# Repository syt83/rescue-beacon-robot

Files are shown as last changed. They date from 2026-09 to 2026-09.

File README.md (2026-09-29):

# Rescue Beacon Robot

RDK X5, Arduino Nano Every, 카메라와 YOLO를 연결해 누운 사람을 찾고
저속 접근한 뒤 멈춰 음향 안내를 재생하는 대회용 ROS 2 프로젝트입니다.
YDLIDAR X4 Pro 코드는 있지만 현재 실물 주행에는 사용하지 않습니다.

## 현재 동작하는 범위

| 기능 | 상태 |
| --- | --- |
| 카메라 → YOLO → ROS 사람 탐지 | RDK X5에서 실측 완료 |
| 카메라 기반 사람 접근, SEARCH → CONFIRM → APPROACH → ALERT | 2026-09-29 바닥 통합 시험에서 접근·ALERT·정지·안내음 확인 |
| LiDAR | `/scan` 발행은 확인했지만 유효 거리 0 문제가 재발해 최종 주행에서 제외 |
| ALERT 이후 정지 유지, 센서/명령 시간 초과 시 정지 | ALERT에서 `/cmd_vel` 선속도·회전속도 0 실측, 오프라인 안전 테스트 통과 |
| Nano Every USB 연결 | 장치 인식 완료 |
| Nano Every 펌웨어와 USB 통신 | 수정 펌웨어 업로드 완료. `READY,1`, `ENC`, `SOUND`, `ACK,BEEP2` 확인 |
| 모터·엔코더 | 왼쪽 방향 설정 수정 후 받침대와 바닥에서 양쪽 전진·정지 확인. 카메라 기반 바닥 통합 주행 확인 |
| ROS ↔ Arduino | 주행 전달을 끈 브리지에서 `/arduino_ready: true`, 정지 상태 `ENC,0,0` 실측 |
| LM393 소리 반응, 스피커 출력 | DFPlayer Pro의 첫 번째 파일 `bbibip.mp3`을 Nano 명령과 ROS 트리거에서 실물 재생 확인. LM393 입력은 별도 시험 필요 |

ROS 제어의 실제 이동 명령은 `mission_controller_node`가
`/cmd_vel`로 발행합니다. 시리얼은 기본적으로 **꺼져 있고**, 시리얼을 켜도
모터 전달은 기본적으로 **꺼져 있습니다**. `ALERT` 상태는 노드 재시작 전까지
유지됩니다.

## 구성

- RDK X5: ROS 2, 카메라, YOLO, LiDAR, 미션 제어
- Arduino Nano Every: PWM/DIR 모터 제어, 엔코더·LM393 입력, DFPlayer Pro 제어
- Cytron MD20A 2개 + RB-35GM 엔코더 모터 2개
- DFPlayer Pro DFR0768 + PAM8403 + 스피커, 128 MB 내장 저장공간

Arduino USB 프로토콜은 `HELLO`/`READY,1`로 펌웨어 버전을 확인합니다.
다른 스케치가 올라가 있으면 ROS 브리지는 모터 명령을 보내지 않습니다.
정확한 핀 제안과 업로드 방법은
[Arduino 펌웨어 안내](firmware/arduino/README.md)에 있습니다.
모터만 확인할 때는 [임시 Arduino 스케치](firmware/arduino/motor_only_diagnostic/motor_only_diagnostic.ino)를
노트북 USB로 업로드하고, [시험 순서](firmware/arduino/README.md)를 따릅니다.

## 실행

1. [대회 실행 및 하드웨어 시험 순서](docs/competition-runbook.md)
2. [코드 전체 안내: 파일별 역할과 읽는 순서](docs/code-guide.md)
3. [ROS 패키지 구조와 토픽](software/ros2/rescue_beacon/README.md)
4. [YOLO 연결](software/perception/README.md)

최종 주행 중 노트북에서 탐지 상자 영상을 보려면
[YOLO 브라우저 모니터](software/perception/README.md#yolo-화면-모니터)를
카메라·YOLO와 함께 실행합니다.

이 장비의 YOLO 런타임과 `best_bayese_640x640_nv12.bin` 모델은 이 저장소 밖에
있습니다. 새 RDK에 복제할 때 두 파일을 따로 준비해야 합니다.

## 구현 범위

현재 거리 판단은 스테레오 깊이가 아니라 YOLO 사람 상자의 높이·폭 비율을
사용합니다. 최종 카메라 주행에는 LiDAR 장애물 정지가 없으며 SLAM/경로
계획도 포함하지 않습니다. LM393 한 개는 소리 유무만 알 수 있으며 방향은 알 수 없습니다.
BNO085 자세 추정과 구조 대상 좌표 보고는 아직 구현되지 않았습니다.
검증된 최종 실행 방법은 [카메라 전용 시험 안내](docs/camera-only-trial.md)를 따릅니다.

## 라이선스

MIT

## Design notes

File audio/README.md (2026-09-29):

# DFPlayer Pro DFR0768 음원 준비

실제로 구매한 모듈은 [DFPlayer Pro DFR0768](https://www.devicemart.co.kr/goods/view?no=13903819)입니다.
**microSD 카드 슬롯이 없고 128 MB 내장 저장공간을 USB-C로 사용합니다.**
[`mp3/0001.mp3`](mp3/0001.mp3)은 약 1.2초짜리 스피커 시험음입니다.
현재 DFPlayer Pro에 복사된 첫 번째 파일은 `bbibip.mp3`입니다. 실물에서
첫 번째 파일 재생 명령으로 이 소리가 나는 것을 확인했습니다.

1. 로봇 메인 전원을 끄고 DFPlayer Pro의 USB-C 단자를 데이터 케이블로 컴퓨터에 연결합니다. Nano Every의 USB 단자가 아닙니다.
2. Windows에서 열린 DFPlayer Pro USB 드라이브의 최상위에 `bbibip.mp3`을 복사합니다. 실제 장비에서는 Windows로 복사를 마쳤습니다. 파일이 여럿이면 첫 번째 파일 번호는 복사 순서에 따라 달라질 수 있으므로 재생 시험으로 확인하세요.
3. 드라이브를 안전하게 꺼낸 뒤 USB-C 케이블을 뽑습니다. Nano에 DFPlayer Pro용 펌웨어가 없다면 [업로드 순서](../firmware/arduino/README.md#빌드와-업로드)를 따릅니다.
4. 다른 시리얼 프로그램을 종료하고 RDK 터미널에 입력합니다.

   ```bash
   cd ~/rescue_ws/rescue-beacon-robot
   python3 scripts/arduino_smoke_test.py --port /dev/ttyACM0 --first-track
   ```

`ACK,BEEP2`는 Arduino가 UART로 첫 번째 파일 재생 명령을 보냈다는 뜻입니다. 스피커에서 실제 소리가 나는지도 확인해야 합니다. 재생 시험 중 바퀴가 움직이면 메인 전원을 즉시 끕니다.

처음 앰프는 뜨거워져 교체했습니다. 교체한 앰프에서는 `PLAY` 버튼으로
“music” 안내음이 들렸고, `--first-track` 시험에서는 원하는 `bbibip.mp3`이
실제로 들렸습니다. `--beep`가 보내는 경로 지정 명령은 이 장비에서 소리를
내지 않았습니다. 따라서 ROS 안내는 검증된 `BEEP,2` → `AT+PLAYNUM=1`을
사용합니다. ROS `/beacon_trigger` 시험에서도 `bbibip.mp3` 재생을 확인했습니다.
현재 Arduino 펌웨어 볼륨 기본값은 20입니다. 다른 파일을
추가하거나 지우면 첫 번째 파일이 바뀔 수 있으므로 다시 들어 보고 확인하세요.

DFPlayer Pro의 USB 파일 복사와 115200 baud AT 명령은 [DFRobot 예제](https://wiki.dfrobot.com/dfr0768/docs/20423)와 [명령 참고서](https://wiki.dfrobot.com/dfr0768/docs/20422)를 따릅니다. 회로도에는 이전 가정인 DFPlayer Mini 심벌이 남아 있어 실제 배선은 Pro 핀 이름으로 다시 확인해야 합니다.

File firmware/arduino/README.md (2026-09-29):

# Arduino Nano Every 펌웨어

## 모터 전원 없이 엔코더 확인

[sensor_only_diagnostic.ino](sensor_only_diagnostic/sensor_only_diagnostic.ino)는
모터 명령을 받지 않고 왼쪽·오른쪽 엔코더의 카운트와 A/B 핀 상태를 보여줍니다.
노트북에 연결한 Nano Every에서만 실행하며, **메인 스위치는 끈 상태로**
유지합니다. 모터 전원과 RDK 전원이 같은 스위치에 묶여 있으므로 RDK에서
실행하는 시험은 아직 진행하지 않습니다.

1. 메인 스위치를 끄고 Nano USB를 Ubuntu 노트북에 연결합니다.
2. Arduino IDE에서 위 파일을 열어 **Arduino Nano Every** 보드와 Nano의
   포트를 선택한 뒤 업로드합니다.
3. 시리얼 모니터를 **115200 baud**로 엽니다. `SENSOR_ONLY_READY` 다음에
   `ENC,<왼쪽>,<오른쪽>,PINS,<LA>,<LB>,<RA>,<RB>,SOUND,<0/1>`이
   반복해서 나오는지 확인합니다.
4. 메인 스위치를 **켜지 않고**, 손으로 왼쪽 바퀴만 천천히 한 바퀴 돌려
   첫 번째 카운트가 변하는지 봅니다. 이어 오른쪽 바퀴만 돌려 두 번째
   카운트가 변하는지 봅니다. 카운트가 증가하는지 감소하는지는 방향에
   따라 달라질 수 있습니다.

카운트가 0에서 바뀌지 않으면 `PINS` 값도 함께 기록합니다. Nano USB만으로
엔코더에 전원이 공급되지 않는 배선일 수 있으므로, 이 결과만으로 엔코더
고장을 판정하지 않습니다. `SOUND`는 회로도의 Arduino_Core 그림에 D10
연결이 표시되지 않아 현재 배선 확인 전에는 참고값일 뿐입니다.

## 모터만 확인하는 임시 스케치

[motor_only_diagnostic.ino](motor_only_diagnostic/motor_only_diagnostic.ino)는
카메라·ROS·RDK 명령 없이 Nano Every에서 MD20A 두 개만 시험합니다.
이전 시험에서 속도 0 명령에도 바퀴가 계속 돌았으므로 **아래 순서 외의 주행
명령은 실행하지 마세요.** 스케치는 부팅 시 PWM을 0으로 설정하지만, 실제
배선이나 드라이버 문제로 바퀴가 도는 것은 소프트웨어가 막지 못합니다.

1. **메인 스위치를 끈 상태에서** Nano USB를 RDK에서 빼서 Ubuntu 노트북에
   연결합니다. Arduino IDE에서 위 `.ino` 파일을 열고 보드를
   **Arduino Nano Every**, 포트를 Nano USB 장치로 선택해 업로드합니다.
   보드가 목록에 없다면 Boards Manager에서 **Arduino megaAVR Boards**를
   설치합니다. 업로드 중에도 메인 스위치는 끈 채 둡니다.
2. Arduino IDE의 시리얼 모니터를 **115200 baud**, 줄 끝은 **Newline**으로
   설정합니다. `STATUS`를 보내 `STATUS,IDLE`이 오는지 확인합니다.
   이때 노트북 USB가 Nano만 켜고 모터 배터리는 꺼진 상태입니다.
3. 차체를 받침대에 고정해 두 바퀴를 띄우고, 손은 바퀴에서 떼고 메인
   스위치에 바로 닿을 수 있게 합니다. 메인 스위치를 켠 뒤 **아무 명령도
   보내지 않고** 확인합니다. 바퀴가 하나라도 돌면 즉시 메인 스위치를
   끄고 더 진행하지 않습니다.
4. 두 바퀴가 가만히 있을 때만 `ARM`을 보내고 5초 안에 `LEFT`를 보냅니다.
   왼쪽만 0.2초 돌고 멈추는지 봅니다. 계속 돌면 메인 스위치를 즉시 끕니다.
   정상이면 다시 `ARM` 다음 `RIGHT`를 보내 오른쪽을 확인합니다.
   `STOP`은 PWM 0 명령이지만, 실제 정지는 눈으로 확인해야 합니다.
5. 시험을 마치면 메인 스위치를 끕니다. 이 임시 스케치는 ROS용
   `READY,1` 프로토콜을 제공하지 않으므로 대회 코드를 쓰려면 아래의
   `rescue_beacon_firmware.ino`를 다시 업로드해야 합니다.

시리얼 모니터에서 보낼 명령은 다음과 같습니다. 한 줄씩 전송합니다.

```text
STATUS
ARM
LEFT
ARM
RIGHT
STOP
```

`ARM`은 다음 한 번의 구동만 허용하고 5초 뒤 만료됩니다. `LEFT`와
`RIGHT`는 PWM 60/255로 최대 0.2초만 구동합니다. 출력 메시지
`PWM_ZERO_COMMAND`는 Arduino가 0을 **명령했다**는 뜻이며, 바퀴가 실제로
멈췄다는 측정값은 아닙니다.

## 구조 로봇 본 펌웨어

`rescue_beacon_firmware/rescue_beacon_firmware.ino`는 RDK X5와 USB 직렬
통신을 하고 Cytron MD20A 2개, 엔코더, LM393, **DFPlayer Pro DFR0768**을 제어합니다.
실제 구매 모듈은 Pro이며, 이전 Mini용 9600 baud 바이너리 명령을
115200 baud AT 명령으로 수정했습니다. 수정한 펌웨어는 다시 업로드해야 합니다.

## 회로도 기준 핀 배치

아래 표는 `hardware/kicad/rescue-beacon-robot.kicad_sch`의
`Arduino_Core` 회로도와 사용자가 공유한 회로도 그림 기준입니다.
실제 배선이 다르면 스케치 맨 위의 핀 상수와 모터 반전 값을 수정한 뒤
업로드하세요.

| Nano Every | 연결 대상 | 코드 상수 |
| --- | --- | --- |
| D3 (PWM) | 왼쪽 MD20A PWM (`PWM_L`) | `LEFT_PWM_PIN` |
| D4 | 왼쪽 MD20A DIR (`DIR_L`) | `LEFT_DIR_PIN` |
| D9 (PWM) | 오른쪽 MD20A PWM (`PWM_R`) | `RIGHT_PWM_PIN` |
| D7 | 오른쪽 MD20A DIR (`DIR_R`) | `RIGHT_DIR_PIN` |
| D2 / D5 | 왼쪽 엔코더 A / B | `LEFT_ENC_A_PIN` / `LEFT_ENC_B_PIN` |
| D6 / D8 | 오른쪽 엔코더 A / B | `RIGHT_ENC_A_PIN` / `RIGHT_ENC_B_PIN` |
| D10 | LM393 DO용 코드 핀; 제공된 `Arduino_Core` 그림에는 연결 표시 없음 | `SOUND_PIN` |
| TX (D1) | DFPlayer Pro RX | `Serial1` |
| RX (D0) | DFPlayer Pro TX (선택, 현재 응답 미사용) | `Serial1` |
| USB | RDK X5 | `Serial`, 115200 baud |

Arduino와 MD20A 2개, DFPlayer Pro, LM393의 **GND는 공통**으로 연결합니다.
LM393 신호선이 D10에 연결되지 않았다면 `SOUND` 값은 실제 소리 상태를
나타내지 않습니다. 음향 감지 시험 전에 이 신호선을 확인하세요.
MD20A의 모터 전원과 모터는 제품 사양에 맞춰 별도로 연결하세요.
모터 전원선을 Nano의 5V 핀에 연결하지 마세요. DFPlayer Pro와 PAM8403은
적합한 안정된 전원을 사용하세요. PAM8403 입력은 DFPlayer Pro의
DAC 출력(DACL/DACR)에 연결하고, Pro의 L+/L- 또는 R+/R- 스피커 출력을
앰프 입력에 연결하지 마세요. 기존 KiCad의 Mini 심벌은 실제 Pro의
핀 배치를 나타내지 않으므로 실물 핀 이름을 기준으로 확인합니다.

Nano Every 핀 기능은 [Arduino 핀도](https://docs.arduino.cc/resources/pinouts/ABX00028-full-pinout.pdf),
PWM/DIR와 자체 테스트 버튼은 [Cytron MD20A 안내](https://www.cytron.io/p-20amp-6v-30v-dc-motor-driver),
DFPlayer Pro 전원·UART·DAC는 [DFRobot 안내](https://wiki.dfrobot.com/dfr0768/)를
기준으로 확인했습니다.

## 음원

USB-C로 Pro 내장 저장공간의 최상위에 `bbibip.mp3`을 넣습니다. `BEEP,2`는
검증된 첫 번째 파일 재생 명령 `AT+PLAYNUM=1`을 보냅니다. `BEEP,1`의
`AT+PLAYFILE=/bbibip.mp3` 경로 재생은 이 장비에서 소리가 나지 않았습니다.
[음원 복사 순서](../../audio/README.md)를
따르세요. Nano Every의 USB 포트로는 Pro에 파일을 복사할 수 없습니다.
`ACK,BEEP2`는 Arduino가 첫 번째 파일 재생 명령을 전달했다는 뜻이며, 실제 소리가
났는지는 귀로 확인해야 합니다.

## 빌드와 업로드

RDK X5에는 [Arduino CLI](https://arduino.github.io/arduino-cli/latest/installation/)
1.5.1과 `arduino:megaavr` 코어 1.8.8을 `~/rescue_ws` 아래에 설치했습니다.
저장소 최상위 경로에서 다음을 실행하세요. 노트북의 Arduino IDE에서
업로드하려면 보드를 **Arduino Nano Every**로 선택하고 보드를 노트북 USB에
연결해야 합니다.
ROS 시리얼 브리지와 시리얼 모니터는 먼저 종료합니다.
현재 Pro용 스케치는 Nano Every 대상 빌드·업로드와 첫 번째 파일
`bbibip.mp3` 재생을 실물 확인했습니다.

```bash
~/rescue_ws/bin/arduino-cli compile --fqbn arduino:megaavr:nona4809 firmware/arduino/rescue_beacon_firmware
~/rescue_ws/bin/arduino-cli upload -p /dev/ttyACM0 --fqbn arduino:megaavr:nona4809 firmware/arduino/rescue_beacon_firmware
```

업로드에서 `jtagmkII_getsync(): sign-on command: status -1`가 반복되면,
Nano Every의 USB 포트를 1200 baud로 열었다 닫아 업로드 모드로 전환한 뒤
바로 업로드 명령을 재시도하세요. 이 장비에서는 그 순서로 성공했습니다.

```bash
python3 -c 'import serial,time; s=serial.Serial("/dev/ttyACM0",1200,timeout=0.1); time.sleep(0.3); s.close()'
~/rescue_ws/bin/arduino-cli upload -p /dev/ttyACM0 --fqbn arduino:megaavr:nona4809 firmware/arduino/rescue_beacon_firmware
```

현재 이 장비의 Nano Every는 `/dev/ttyACM0`이고 LiDAR는 `/dev/ttyUSB0`입니다.
다른 장비에서는 `ls -l /dev/serial/by-id/`로 포트를 다시 찾으세요.
업로드 후 모터 전원을 끈 상태에서:

```bash
python3 scripts/arduino_smoke_test.py --port /dev/ttyACM0
```

`READY,1`, `ENC,...`, `SOUND,...`가 나와야 합니다. 2026-09-27에 업로드 후
`READY,1`, `ENC,0,0`, `SOUND,0`을 확인했습니다. 이전 스케치의
`Nano Every Ready` 출력이 보이면 업로드가 완료되지 않은 상태입니다.

## 직렬 프로토콜과 안전 동작

| 방향 | 메시지 | 의미 |
| --- | --- | --- |
| RDK → Nano | `HELLO` | 펌웨어 버전 요청 |
| Nano → RDK | `READY,1` | 호환 프로토콜 응답 |
| RDK → Nano | `CMD,<m/s>,<rad/s>` | 차동 구동 명령 |
| RDK → Nano | `BEEP,1` | Pro 내장 저장공간의 `/bbibip.mp3` 재생 요청 |
| RDK → Nano | `BEEP,2` | 실물에서 검증된 첫 번째 파일 재생 요청. ROS 기본 안내 명령 |
| Nano → RDK | `ENC,<left>,<right>` | 엔코더 누적 카운트 |
| Nano → RDK | `SOUND,<0/1>` | LM393 디지털 입력 |
| Nano → RDK | `ACK,BEEP` / `ACK,BEEP2` / `ERR,CMD` | 재생 명령 전달 / 잘못된 주행 명령 |

부팅 시 PWM은 0입니다. 유효한 `CMD`가 0.5초 동안 오지 않으면 PWM을 0으로
만듭니다. 명령 크기가 상한을 넘거나 형식이 틀리면 정지합니다.
이는 소프트웨어 정지 장치이며 실제 시험에서는 모터 전원 차단 수단도
준비해야 합니다.
2026-09-27 신호 GND 선을 재연결한 뒤 바퀴가 속도 0 명령에도 계속 돌아
메인 스위치로 정지했습니다. 이후 사용자가 배선을 다시 하고 양쪽 모터의
직선·곡선·회전 주행과 엔코더 동작을 확인했습니다. ROS 브리지의 1회
전진 명령으로도 양쪽 바퀴가 잠깐 돌고 멈췄습니다. 2026-09-29에는 왼쪽
방향 설정을 수정하고 카메라 전용 바닥 주행의 접근·정지·안내음을 확인했습니다.
배선 오류나 접촉 불량에는
소프트웨어 정지 명령이 통하지 않을 수 있으므로 물리 전원 스위치를
사용할 수 있게 둡니다.

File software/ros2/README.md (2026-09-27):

# ROS 2 소프트웨어

`rescue_beacon/`은 RDK X5에서 실행하는 Python ROS 2 패키지입니다.
실제 구현 노드는 `lidar_nav_node`, `person_follow_node`,
`mission_controller_node`, `serial_bridge_node`입니다.

```bash
cd ~/rescue_ws/rescue-beacon-robot
bash scripts/build_ros.sh
bash scripts/run_mission.sh
```

기본 실행은 Arduino 시리얼과 모터 전달이 모두 꺼져 있습니다.
전체 실행 및 하드웨어 순서는
[대회 실행 안내](../../docs/competition-runbook.md),
노드와 토픽은 [패키지 README](rescue_beacon/README.md)를 보세요.

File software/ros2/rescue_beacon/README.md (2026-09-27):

# Rescue Beacon ROS 2 패키지

RDK X5에서 아래 네 노드가 동작합니다.

```text
/scan ── lidar_nav_node ── /search_cmd_vel ──┐
                                             ├─ mission_controller_node ── /cmd_vel
/rescue_yolo_detections ── person_follow_node ┤                └─ /beacon_trigger
                         └─ /person_cmd_vel ┘
                                                      serial_bridge_node
                                                      └─ Nano Every USB
```

`mission_controller_node`가 최종 `/cmd_vel`의 유일한 정상 퍼블리셔입니다.
상태는 `SEARCH → CONFIRM → APPROACH → ALERT`이며, ALERT는 노드를
재시작할 때까지 유지됩니다. 사람 탐지 입력과 LiDAR 스캔이 오래되거나
유효하지 않으면 정지합니다. 탐색·추적 입력과 시리얼 명령에도 각각
시간 초과 처리가 있습니다.

## 실행 인자

`bash scripts/run_mission.sh`는 저장소 최상위 경로에서 실행합니다.

| 인자 | 기본값 | 의미 |
| --- | --- | --- |
| `enable_person` | `true` | 사람 추적 노드 실행 |
| `enable_serial` | `false` | Arduino USB 연결 |
| `enable_motion` | `false` | 시리얼 브리지가 0 이외의 모터 명령 전달 |
| `serial_port` | `/dev/ttyACM0` | Arduino 포트 |

`enable_motion:=true`는 `enable_serial:=true`와 함께 사용합니다.
시리얼 브리지는 `READY,1` 응답을 받은 뒤에만 `CMD`와 `BEEP`를
보냅니다. 다른 스케치가 설치된 보드에는 모터 명령을 보내지 않습니다.
`/beacon_trigger`는 ALERT 상태를 반복 발행하고, 브리지는 상승 시
한 번만 재생 요청을 보냅니다. 연결이 끊겼다가 복구되면 ALERT 재생을
다시 요청합니다.

## 토픽

| 토픽 | 타입 | 의미 |
| --- | --- | --- |
| `/scan` | `sensor_msgs/msg/LaserScan` | LiDAR 입력 |
| `/rescue_yolo_detections` | `ai_msgs/msg/PerceptionTargets` | YOLO 사람 상자 |
| `/search_cmd_vel` | `geometry_msgs/msg/Twist` | LiDAR 탐색 후보 |
| `/person_cmd_vel` | `geometry_msgs/msg/Twist` | 사람 접근 후보 |
| `/person_detected`, `/person_close` | `std_msgs/msg/Bool` | 탐지와 근접 프록시 |
| `/mission_state` | `std_msgs/msg/String` | 상태 머신 |
| `/cmd_vel` | `geometry_msgs/msg/Twist` | 최종 주행 명령 |
| `/beacon_trigger` | `std_msgs/msg/Bool` | 음향 안내 상태 |
| `/arduino_ready` | `std_msgs/msg/Bool` | 호환 펌웨어 통신 여부 |
| `/arduino_telemetry` | `std_msgs/msg/String` | ENC/ACK/ERR 직렬 메시지 |
| `/sound_detected` | `std_msgs/msg/Bool` | LM393 디지털 입력 |

사람 상자의 높이 비율로 접근을 멈추므로 실제 거리 센서는 아닙니다.
단일 LM393의 소리 입력은 모니터링만 하며 방향 탐색에는 쓰지 않습니다.
하드웨어별 실행 순서는
[대회 실행 안내](../../../docs/competition-runbook.md)에 있습니다.

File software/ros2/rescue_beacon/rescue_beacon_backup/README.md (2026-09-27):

# Rescue Beacon ROS2 Package

RDK X5에서 실행되는 Rescue Beacon Robot용 ROS2 패키지입니다.

현재는 YDLIDAR X4 Pro의 `/scan` 데이터를 이용한
기본 장애물 감지 및 회피 명령 생성 기능을 구현하고 있습니다.

## 현재 구현

```text
YDLIDAR X4 Pro
      ↓
    /scan
      ↓
 lidar_nav_node
      ↓
전방 / 좌측 / 우측 거리 판단
      ↓
   /cmd_vel

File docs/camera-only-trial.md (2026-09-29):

# LiDAR 없이 카메라 사람 접근 시험

이 시험은 X4 Pro가 거리 0만 보고할 때 사용하는 **2초짜리 저속 시험**이다.
YOLO 모델은 `fallen`, `sit`, `standing`을 분류한다. 이 시험에서는 **`fallen`
상자만** 추적한다. 화면에는 시험 대상 한 명만 들어오게 한다.
모터는 초속 0.05m, 회전 초속 0.20rad 이하로 제한한다. 정상 종료와
`ALERT`에서는 약 0.5초 동안 속도를 줄이고, 통신이 끊기면 즉시 정지한다.
위 2초 시험에서는 음원을 재생하지 않는다.

LiDAR 장애물 감지는 이 모드에서 사용하지 않는다. 경로에 물건이 없고,
로봇과 사람 사이가 1~2m일 때만 시험한다. 다른 한 명이 화면 밖에서
메인 스위치를 바로 끌 수 있어야 한다. 배터리가 뜨겁거나 부풀었거나
이상한 냄새가 나면 실행하지 않는다.

RDK 터미널을 다음 순서로 연다. LiDAR 터미널과 기존 미션 터미널은 종료한다.

| 터미널 | 실행 명령 |
| --- | --- |
| 1 카메라 | `cd ~/rescue_ws/rescue-beacon-robot && bash scripts/run_camera.sh` |
| 2 YOLO | `cd ~/rescue_ws/rescue-beacon-robot && bash scripts/run_yolo.sh` |
| 3 영상 | `cd ~/rescue_ws/rescue-beacon-robot && bash scripts/run_yolo_monitor.sh --host 0.0.0.0` |
| 4 시험 | `cd ~/rescue_ws/rescue-beacon-robot && python3 scripts/run_camera_only_trial.py` |

노트북 브라우저에서 `http://<RDK_IP>:8088`을 열고, 누운 사람의 상자에
`fallen`이라고 표시되는지 먼저 확인한다. `sit` 또는 `standing`만 보이면
주행하지 않는다. 터미널 4에서 주의사항을 읽고 `RUN`을
입력하면 Arduino `READY,1` 확인 후 최대 2초 동안만 접근한다. 종료되면
두 바퀴가 실제로 멈췄는지 눈으로 확인한다. `Ctrl+C`나 메인 스위치로도
즉시 중단할 수 있다. 바퀴가 계속 돌면 메인 스위치를 끈다.

`fallen` 상자 높이가 화면의 72% 또는 폭이 75%가 3프레임 연속 유지되면
`ALERT`로 전환해 정지한다. 한 프레임만 커지면 감속하지만 도착으로 확정하지 않는다.
화면 점유율은 실제 거리가 아니다. 이 시험이 움직임과 정지를 확인해도
사람 앞에서 정확한 거리로 멈추는 기능은 검증되지 않는다.

## 사람 앞까지 접근 시험

2초 시험에서 양쪽 바퀴의 이동과 감속 정지, 배터리 온도를 확인했다면 같은
터미널 1~3을 켜 둔 채 터미널 4에서 다음 명령을 실행한다.

```bash
cd ~/rescue_ws/rescue-beacon-robot
python3 scripts/run_camera_approach.py
```

로봇 앞 약 2m에 누운 사람 한 명을 두고 화면에서 `fallen` 표시를 확인한다.
`RUN` 입력 후 `ALERT`가 나올 때까지 같은 저속으로 접근한다. 상자가
정지 기준에 못 미쳐도 Arduino 준비 후 30초에 자동 감속 정지한다.
30초 동안 명령상 최대 전진 거리는 약 1.5m이며 실제 이동 거리는 바퀴와
바닥 상태에 따라 달라진다. 사람이 로봇에 닿기 전에 보조자가 화면과
실제 거리를 함께 보고 필요하면 메인 스위치를 끈다. `fallen box` 로그의
폭·높이 비율은 카메라 추정값이며 미터 단위 거리가 아니다.

이전 시험에서는 상자 폭이 36% 부근에서 한 프레임에 69%로 뛰어
`ALERT`가 조기에 발생했다. `fallen` 탐지가 끊기는 현상도 있었으므로,
화면에서 상자가 사라진다면 로봇은 멈췄다가 다시 탐지할 때 접근한다.
조명·자세·카메라 시야 때문에 모델이 계속 놓치는 경우에는 추론 모델의
데이터와 현장 영상 확인이 필요하다. 임의로 신뢰도 문턱을 낮춰 주행을
계속시키지 않는다.

## 안내음까지 묶은 시험

DFPlayer Pro 첫 번째 파일 `bbibip.mp3`은 Nano 명령과 ROS 트리거로 각각
재생을 확인했다. 두 기능을 한 번에 확인할 때는 같은 터미널 1~3을 켜 두고,
터미널 4에서 아래 명령을 실행한다. 기존 시리얼 브리지·미션이 실행 중이면
먼저 종료한다.

2026-09-29 첫 바닥 통합 시험에서는 전진 명령에 좌우 바퀴가 반대로 돌았다.
Nano 펌웨어의 왼쪽 모터 방향 값을 반전한 뒤, 받침대에서 0.3초 전진 명령으로
양쪽 바퀴의 전진·정지를 확인했다. 이어서 바닥 2초 시험에서 전진·정지,
카메라와 음향을 합친 시험에서 `APPROACH → ALERT`·정지·`bbibip.mp3`
재생을 실제로 확인했다. LiDAR는 이 최종 주행에 사용하지 않는다.

```bash
cd ~/rescue_ws/rescue-beacon-robot
python3 scripts/run_camera_audio_trial.py
```

`RUN` 입력 후 `fallen` 대상에 저속 접근하고, `ALERT`가 되면 감속 정지하며
첫 번째 음원을 재생한다. 30초 안에 ALERT가 되지 않으면 자동 감속 정지한다.
LiDAR 장애물 감지가 없는 시험이므로 경로를 비우고 보조자가 메인 전원
스위치를 바로 끌 수 있게 한다. 종료 뒤 바퀴 정지와 앰프·배터리 온도를
직접 확인한다.

## 정지 거리 측정

카메라 상자 크기는 실제 거리와 일치하지 않는다. 주행 시험을 종료하고
로봇을 원하는 정지 간격(예: 사람과 0.5m)에 놓은 뒤 아래 명령으로
8초 동안 `fallen` 상자 비율과 탐지율을 측정한다. 이 명령은 모터 노드를
실행하지 않는다. 카메라와 YOLO는 켜 둔다.

```bash
source /opt/tros/humble/setup.bash
cd ~/rescue_ws/rescue-beacon-robot
python3 scripts/calibrate_camera_stop.py
```

출력의 영상 프레임 수, fallen 탐지 프레임 수, 폭·높이 중앙값을 보고
정지 기준을 정한다. 누운 사람이 화면에 보이는데도 탐지율이 낮으면
정지 수치를 더 조정하기 전에 카메라 화면과 모델을 확인한다.

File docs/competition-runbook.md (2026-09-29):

# 대회 실행 및 하드웨어 시험 순서

기준 장비는 `/home/sunrise/rescue_ws/rescue-beacon-robot`에 이 저장소가 있고,
ROS 2 Humble/TROS, `~/ydlidar_ros2_ws`,
`~/rdk_model_zoo/samples/vision/ultralytics_yolo/runtime/python/ros_yolo_live.py`,
`~/best_bayese_640x640_nv12.bin`이 설치된 RDK X5입니다.
다른 장비에서는 이 외부 파일과 모델을 따로 준비하세요. 모델은 GitHub
저장소에 포함되지 않습니다.

이전 시험에서 속도 0 명령에도 바퀴가 돌아 메인 스위치로 정지한 적이
있습니다. 이후 사용자가 배선을 다시 연결해 양쪽 바퀴의 직선·곡선·회전
주행과 엔코더 동작을 확인했습니다. 받침대 위에서 ROS 브리지의 1회
전진 명령으로 양쪽 바퀴가 잠깐 돌고 멈춘 것도 확인했습니다.
ROS 회전 명령에서는 두 바퀴가 서로 반대 방향으로 잠깐 돌고 멈췄습니다.
2026-09-29 왼쪽 모터 방향을 수정한 뒤 카메라 전용 저속 바닥 주행에서
사람 접근·ALERT 정지·안내음 재생을 확인했습니다. LiDAR는 이 주행에
사용하지 않았습니다. 전원을 켰을 때 명령 없이
바퀴가 돌면 즉시 메인 스위치를 끄고 시험을 중단합니다.

## 0. 빌드

```bash
cd ~/rescue_ws/rescue-beacon-robot
bash scripts/build_ros.sh
```

빌드가 끝난 뒤에도 각 실행 터미널은 별도로 켜 둡니다. 종료할 때는 각
터미널에서 `Ctrl+C`를 누릅니다.

## 0-1. 메인 전원을 끈 채 엔코더만 확인

엔코더를 다시 독립적으로 확인할 때는 노트북 USB로 Nano를 켜고
[센서 전용 Arduino 스케치](../firmware/arduino/README.md#모터-전원-없이-엔코더-확인)를
사용합니다. 왼쪽·오른쪽 바퀴를 손으로 각각 돌려 엔코더 카운트가 변하는지
확인합니다. 이 스케치에는 모터 구동 명령이 없습니다. RDK와 모터는 같은
메인 스위치에 연결되어 있으므로, Nano만 켤 때는 메인 스위치를 끕니다.

## 1. 모터 전달을 끈 ROS 시험

아래 네 터미널을 순서대로 실행합니다. 미션 실행 기본값은
`enable_serial:=false`이므로 Arduino로 명령을 보내지 않습니다.

| 터미널 | 명령 | 확인할 것 |
| --- | --- | --- |
| 1 카메라 | `cd ~/rescue_ws/rescue-beacon-robot && bash scripts/run_camera.sh` | `/image_left_raw` |
| 2 YOLO | `cd ~/rescue_ws/rescue-beacon-robot && bash scripts/run_yolo.sh` | `/rescue_yolo_detections` |
| 3 LiDAR | `cd ~/rescue_ws/rescue-beacon-robot && bash scripts/run_lidar.sh` | `/scan` |
| 4 미션 | `cd ~/rescue_ws/rescue-beacon-robot && bash scripts/run_mission.sh` | `/mission_state`, `/cmd_vel` |
| 5 YOLO 화면 | `cd ~/rescue_ws/rescue-beacon-robot && bash scripts/run_yolo_monitor.sh --host 0.0.0.0` | 브라우저의 탐지 상자 영상 |

RDK 모니터의 브라우저에서 `http://127.0.0.1:8088`을 열거나, 노트북에서는
RDK의 `hostname -I`로 확인한 주소로 `http://<RDK_IP>:8088`을 엽니다.
모니터는 `/yolo/image_annotated/compressed`를 읽기만 하고 모터 명령을
보내지 않습니다. 카메라·YOLO 실행 뒤에 열어 둡니다.

터미널 6에서:

```bash
source /opt/tros/humble/setup.bash
source ~/rescue_ws/rescue-beacon-robot/software/ros2/install/setup.bash
ros2 topic hz /scan
ros2 topic hz /rescue_yolo_detections
ros2 topic echo /mission_state --once
ros2 topic echo /cmd_vel --once
```

사람이 카메라에 충분히 크게 잡히면
`SEARCH → CONFIRM → APPROACH → ALERT`를 확인합니다.
`ALERT`에서 `/cmd_vel`은 0이며, 사람 영상이 사라져도 ALERT를 유지합니다.
새 탐색은 **터미널 4를 Ctrl+C로 종료하고 다시 실행**해야 시작합니다.
`stop_height_ratio: 0.72`는 1080픽셀 영상에서 사람 상자 높이 약
778픽셀을 뜻하며 실제 미터 거리가 아닙니다.

2026-09-27 실물 ROS 시험에서 `/scan` 약 11.1 Hz,
`SEARCH → CONFIRM → APPROACH → ALERT`를 확인했습니다. `ALERT`에서
`/beacon_trigger: true`, `/cmd_vel`의 `linear.x: 0.0`과
`angular.z: 0.0`도 확인했습니다. `person_close`는 실시간 탐지값이어서
ALERT 이후 사람이 화면에서 멀어지면 `false`가 될 수 있지만,
미션 상태는 ALERT로 유지됩니다. 미션을 다시 시작하면 상태는 SEARCH부터
시작하므로, `/cmd_vel` 회전값은 **같은 실행에서 ALERT를 확인한 뒤에만**
ALERT 정지 시험의 결과로 해석합니다.

## 2. Arduino 펌웨어 업로드

먼저 [펌웨어 README](../firmware/arduino/README.md)의 회로도 핀 배치와 실제
배선을 맞춥니다. 주행 노드를 종료하고 차체를 고정한 상태에서 Arduino Nano
Every용 스케치를 업로드합니다. 이 장비는 RDK와 모터가 메인 스위치를 공유하므로
모터 전원만 따로 끌 수 없습니다. `Nano Every Ready` 문구가 보이면 이전 스케치가 실행 중인
것이므로 [펌웨어 README](../firmware/arduino/README.md)의 업로드 절차를
진행하세요. 2026-09-27에 이 장비에는 저장소 펌웨어를 업로드하고
`READY,1` 통신을 확인했습니다.

업로드 후, 다른 시리얼 프로그램이 모두 종료된 상태에서:

```bash
cd ~/rescue_ws/rescue-beacon-robot
python3 scripts/arduino_smoke_test.py --port /dev/ttyACM0
```

`READY,1`, `ENC,...`, `SOUND,...`가 나와야 합니다. 이 스크립트는
주행 명령으로 0만 보냅니다. 포트가 바뀌면
`ls -l /dev/serial/by-id/`로 Nano Every를 찾아 `--port`에 넣습니다.
`/dev/ttyUSB0`은 이 장비의 LiDAR이므로 Arduino 포트로 쓰지 않습니다.

## 3. 음향·센서 시험 (모터 주행 잠금)

DFPlayer Pro DFR0768과 PAM8403을 연결하고 USB-C로 내장 저장공간에
`/bbibip.mp3`을 복사합니다. 저장소의 [테스트 음원과 복사 순서](../audio/README.md)를
사용할 수 있습니다. 먼저 ROS 없이 재생 명령을 시험합니다.

```bash
cd ~/rescue_ws/rescue-beacon-robot
python3 scripts/arduino_smoke_test.py --port /dev/ttyACM0 --first-track
```

`ACK,BEEP2`는 Arduino가 첫 번째 파일 재생 명령을 보냈다는 뜻입니다. 실제 소리가 나는지
귀로 확인하세요. 무음이면 Pro용 펌웨어 업로드, 파일 순서, 전원,
DAC→앰프, 스피커를 확인합니다.

ROS 연결 시험은 별도 터미널에서:

```bash
cd ~/rescue_ws/rescue-beacon-robot
bash scripts/run_serial_bridge.sh
```

이 스크립트는 `enable_motion=false`로 시작합니다. 다른 터미널에서:

```bash
source /opt/tros/humble/setup.bash
ros2 topic echo /arduino_ready --once
ros2 topic echo /arduino_telemetry --once
ros2 topic echo /sound_detected --once
ros2 topic pub --once /beacon_trigger std_msgs/msg/Bool "{data: true}"
```

`/arduino_ready`가 `true`여야 합니다. `/arduino_telemetry`에
`ENC,...`와 재생 시 `ACK,BEEP2`가 보입니다. LM393은
`/sound_detected`에 0/1로 나타납니다. LM393 한 개로는 소리 방향을
추정할 수 없어서 미션 주행에는 아직 쓰지 않습니다.
시험이 끝나면 시리얼 브리지 터미널에서 `Ctrl+C`를 누릅니다.

## 4. 모터·엔코더 시험 (바퀴를 띄운 상태)

**이전 문제와 현재 상태:** 2026-09-27 왼쪽 MD20A의 GND 선을 다시 꽂은 뒤
바퀴가 계속 돌았습니다. 당시 어느 쪽 바퀴가 돌았는지는 왼쪽 회전만으로
확정할 수 없습니다. 주행 프로세스가 없었고 속도 0 명령을 두 번 보내도
멈추지 않아 메인 스위치로 정지했습니다. 이후 사용자가 배선을 다시 하고
양쪽 모터의 직선·곡선·회전 주행과 엔코더 동작을 확인했습니다. 이 결과는
사용자 보고입니다. 이후 ROS 브리지로 1회 전진 명령을 보내 양쪽 바퀴가
잠깐 돌고 멈춘 것을 확인했습니다. ROS 회전에서도 두 바퀴가 반대 방향으로
잠깐 돌고 멈췄습니다. 자율 주행은 남아 있습니다.

다음 시험부터 실행 명령을 사용자에게 먼저 보여주고, 사용자가 자신의
터미널에서 직접 실행합니다. 스크립트는 시험 조건을 보여준 뒤 `RUN` 입력을
받아야 구동하고 기본 실행 시간은 0.5초입니다. 해당 터미널의 `Ctrl+C`로
스크립트를 중단할 수 있습니다. `Ctrl+C`나 속도 0 명령으로도 바퀴가 멈추지 않으면 즉시 메인
스위치를 끕니다. 이 장비는 RDK와 모터가 같은 스위치를 사용하므로 원격
연결도 끊깁니다.

모터 드라이버·엔코더 배선을 확인하고, 바퀴가 지면에 닿지 않도록
차체를 고정합니다. 메인 전원 스위치에 손이 닿도록 합니다.
먼저 ROS 없이 Arduino만 시험합니다. 배선이 확인된 뒤 아래 명령을 사용자
터미널에서 실행하면 호환 펌웨어와 정지 상태를 확인하고 0.5초간 0.04 m/s
전진 명령을 보낸 뒤 속도 0 명령을 보냅니다. 실제 정지는 눈으로 확인합니다.

```bash
cd ~/rescue_ws/rescue-beacon-robot
python3 scripts/arduino_motor_test.py --port /dev/ttyACM0 --wheels-up
```

두 바퀴가 전진 방향으로 돌고 멈추는지, `Encoder delta`의 좌우 값이 모두
변하는지 확인하세요. 모터가 멈추지 않으면 즉시 메인 전원을 끕니다.
배선을 만질 때도 메인 전원을 끕니다.

2026-09-27 시험에서는 오른쪽 바퀴만 돌았고 좌우 엔코더 값은 모두 0이었습니다.
왼쪽만 명령한 두 번의 시험에서는 어느 바퀴도 돌지 않았습니다. 이후
MD20A 자체 테스트 버튼으로 양쪽 바퀴가 각각 도는 것을 확인했습니다.
자체 테스트 버튼은 누르는 동안 모터를 최고 속도로 돌리므로 차체를
안정적으로 고정하고 아주 짧게 누릅니다. 모터와 드라이버의 전원·출력
경로는 동작합니다. 왼쪽만 0.5초 명령을 보낸 추가 시험에서도 왼쪽 바퀴와
MD20A 출력 LED가 모두 반응하지 않았습니다. 이후 배선을 다시 한 뒤
양쪽 구동을 확인했습니다.
배선을 바꾸기 전에는 메인 전원을 끕니다.
초기 시험에서 좌우 엔코더 값은 모두 0이었지만, GND 재연결 후 정지 명령
시험에서는 `ENC,-29,-9`, `ENC,-32,-17`이 읽혔습니다. 이후 사용자가 배선을
다시 하고 엔코더 동작을 확인했습니다. 당시 초기 카운트만으로는 좌우
엔코더와 실제 바퀴의 대응 관계를 판단하지 않았습니다.
MD20A의 자체 테스트 버튼과 출력 LED는
[제조사 데이터시트](https://cdn.robotshop.com/media/c/cyt/rb-cyt-254/pdf/md20a_datasheet.pdf)에 나옵니다.

카메라·LiDAR·미션 노드는 종료하고 `ros2 topic info /cmd_vel`에서
기존 퍼블리셔가 없는지 확인합니다.

터미널 A:

```bash
cd ~/rescue_ws/rescue-beacon-robot
bash scripts/run_serial_bridge.sh --enable-motion
```

모터·엔코더가 모두 정상 확인되고 `/arduino_ready: true`가 된 뒤 터미널 B에서 짧은
저속 명령을 보냅니다.

```bash
source /opt/tros/humble/setup.bash
ros2 topic pub --once /cmd_vel geometry_msgs/msg/Twist \
  '{linear: {x: 0.10}, angular: {z: 0.0}}'
ros2 topic pub --once /cmd_vel geometry_msgs/msg/Twist \
  '{linear: {x: 0.0}, angular: {z: 0.0}}'
```

명령이 끝난 뒤 0.5초 이내에 두 바퀴가 멈추는지, 같은 방향으로 도는지,
`/arduino_telemetry`의 `ENC` 값이 변하는지 확인합니다. 잘못된 방향이면
펌웨어의 `LEFT_MOTOR_INVERT`/`RIGHT_MOTOR_INVERT`와 실제 모터 극성을
조정하고 재업로드합니다. 장치가 멈추지 않으면 즉시 메인 전원을 끕니다.

## 5. 전체 통합

1. 터미널 1~3에서 카메라, YOLO, LiDAR를 실행하고 터미널 5의 YOLO
   화면을 브라우저에 띄워 탐지 상자를 보면서 진행합니다.
2. 터미널 4에서 먼저 `bash scripts/run_mission.sh enable_serial:=true`를
   실행합니다. 이때 **모터 전달은 여전히 꺼져 있습니다**.
3. `/arduino_ready: true`, 센서 토픽, `ALERT`에서 실제 음향 안내를
   확인합니다. 새 시험마다 터미널 4를 재시작합니다.
4. 바퀴를 띄운 상태에서
   아래의 시간 제한 시험을 사용해 모터 방향과 정지를 확인합니다. 기존
   미션과 브리지를 먼저 종료해야 합니다. Arduino가 `READY,1`을 알린 후
   기본 2초 동안만 모터 전달을 켭니다. 터미널에서 `RUN`을 입력해야 시작하며,
   바퀴가 멈추지 않으면 즉시 메인 전원 스위치를 끕니다.

   ```bash
   cd ~/rescue_ws/rescue-beacon-robot
   python3 scripts/run_integrated_stand_test.py
   ```
5. 마지막으로 넓고 사람이 없는 시험 공간에서 바닥의 짧은 직진을 먼저
   검증합니다. 받침대 시험처럼 `RUN`을 입력해야 시작하고 Arduino READY 후
   기본 2초 안에 자동 종료합니다. 전방 1m를 비우고 메인 스위치를 바로
   끌 수 있는 위치에서 실행합니다.

   ```bash
   cd ~/rescue_ws/rescue-beacon-robot
   python3 scripts/run_integrated_floor_test.py
   ```

   두 바퀴가 실제로 멈춘 뒤 사람 탐색·접근 주행을 별도 시험합니다.
   사람이 있는 방향으로 접근할 때는 바운딩박스 기반 정지값
   `software/ros2/rescue_beacon/config/rescue_beacon.yaml`의
   `stop_height_ratio`를 실제 장착 높이와 시야에 맞게 조정합니다.
   목표 사람은 로봇 전방 1~2m에 서고, 다른 사람은 전원 스위치 옆에서
   노트북 YOLO 화면을 관찰합니다. 아래 명령은 Arduino READY 후 최대 8초,
   `ALERT`가 나오면 정지 상태를 1초 관찰한 뒤 ROS를 종료합니다.

   ```bash
   cd ~/rescue_ws/rescue-beacon-robot
   python3 scripts/run_person_mission_trial.py
   ```

새 Nano를 연결했거나 첫 바닥 시험을 할 때는 다음 저속·무음 옵션을 사용합니다.
시험 전에 `bash scripts/build_ros.sh`로 ROS 패키지를 빌드하고 기존 미션 및
시리얼 브리지는 종료합니다. `--slow`는 Arduino로 전송하기 직전에 전진 속도를
0.05 m/s, 회전 속도를 0.20 rad/s 이하로 함께 줄이고, `--no-audio`는 ALERT에서도
`BEEP,2`를 보내지 않습니다. 두 옵션을 빼면 기존 속도와 음향 설정을 사용합니다.
각 시험은 `RUN`을 입력해야 시작합니다.

```bash
cd ~/rescue_ws/rescue-beacon-robot
python3 scripts/run_integrated_floor_test.py --slow --no-audio
```

사람이 화면에 잘못 잡혀 로봇이 회전하는지 확인할 때는 `--search-only`를
추가합니다. 이 옵션은 사람 추적을 끄고 LiDAR 탐색 명령만 모터로 전달합니다.
시험 로그에는 Arduino로 보낸 전진·회전 명령이 출력되므로, 명령 자체가
회전이었는지 바퀴의 실제 속도 차이였는지 구분할 수 있습니다.

```bash
python3 scripts/run_integrated_floor_test.py --slow --no-audio --search-only
```

2초 시험에서 두 바퀴가 전진·정지하는 것을 확인한 뒤, 앞에 사람이 서 있는
최종 접근 시험을 같은 저속으로 실행합니다. 최대 8초 또는 ALERT 후 1초에
자동 종료됩니다. 모터가 멈추지 않으면 메인 스위치를 즉시 끕니다.

```bash
cd ~/rescue_ws/rescue-beacon-robot
python3 scripts/run_person_mission_trial.py --slow --no-audio
```

LiDAR 스캔이 끊기거나 전방 측정이 유효하지 않으면 ROS가 정지 명령을
보냅니다. ROS `/cmd_vel`이 끊기면 브리지가 0을 보내고, USB 통신이
끊기면 Arduino의 0.5초 감시 시간이 PWM을 0으로 만듭니다. 전원 차단
수단은 별도로 유지합니다.
X4 Pro가 계속 0 거리만 보고할 때의 별도 짧은 시험은
[카메라 전용 2초 시험](camera-only-trial.md)을 따릅니다.
카메라 전용 접근에서 `fallen` 사람 탐지 → 저속 접근 → `ALERT` 정지 →
`bbibip.mp3` 재생까지 묶어 시험할 때는 아래 명령을 사용합니다. LiDAR 장애물
정지가 없는 모드이므로 이동 경로와 사람 앞을 비우고, 보조자가 메인 전원
스위치를 잡습니다. 바퀴가 멈추지 않으면 즉시 메인 전원을 끕니다. 실행 전
별도로 켜 둔 시리얼 브리지와 미션을 종료하고, 카메라·YOLO와 노트북 모니터를
켜서 `fallen` 상자를 확인합니다. 최대 30초, 0.05 m/s 또는 ALERT 후 1초에
자동 종료되며 감속 정지를 요청합니다.

```bash
cd ~/rescue_ws/rescue-beacon-robot
python3 scripts/run_camera_audio_trial.py
```

2026-09-29 실물 시험에서 왼쪽 모터 방향을 수정한 뒤 바닥 전진·정지와
`APPROACH → ALERT`·정지·`bbibip.mp3` 재생을 확인했습니다. 최종 시험은
LiDAR 없이 카메라 전용 모드로 마쳤습니다. `/scan`은 발행됐지만 유효 거리
0 문제가 재발했으므로 LiDAR 장애물 정지 기능은 최종 시험에 포함되지
않았습니다.

전방 0.50m 이내에 유효한 장애물 측정값이 있으면 직선·회전 속도를 모두
0으로 만듭니다.
이 로봇은 LiDAR의 원시 스캔 약 180°가 차체 정면입니다. 실제 정면에 세운
상자는 원시 스캔 173° 부근에서 0.43m로 측정됐습니다. 따라서
`rescue_beacon.yaml`의 두 `scan_yaw_offset_deg`를 180.0으로 설정했습니다.
LiDAR를 다시 장착하면 정면 물체의 원시 각도를 확인하고 두 값을 함께
고쳐야 합니다. 스캔 높이에 닿지 않는 낮은 물체는 감지되지 않습니다.
2026-09-27 모터 전달을 끈 통합 시험에서 정면 상자 0.43m일 때
`SEARCH` 상태의 `/cmd_vel`은 직선·회전 모두 0이었고, 상자를 치우자
전진 0.14m/s로 돌아왔습니다.

## 코드 검증

하드웨어 없이 실행할 수 있는 ROS 안전 동작 테스트:

```bash
cd ~/rescue_ws/rescue-beacon-robot
source /opt/tros/humble/setup.bash
python3 -m unittest discover -s software/ros2/rescue_beacon/test -p "test_*.py" -v
```

Arduino Nano Every 대상 컴파일 명령과 업로드 결과는
[펌웨어 README](../firmware/arduino/README.md)에 있습니다.

## GitHub에 공유하기

모델 바이너리와 외부 YOLO 런타임은 저장소에 들어 있지 않습니다.
기존 코드 전체가 들어 있는 `fix/md20a-safe-bringup` 브랜치에 변경을 게시하고
Pull Request로 검토합니다. `main`에 직접 푸시하지 않습니다.
기여자 목록과 프로필의 커밋 기여는 GitHub 계정에 연결된 이메일로 작성한
커밋이 기본 브랜치에 병합되어야 반영됩니다. 자세한 조건은
[GitHub 기여자 안내](https://docs.github.com/en/repositories/viewing-activity-and-data-for-your-repository/viewing-a-projects-contributors)에 있습니다.
로컬에서 게시할 때:

```bash
cd ~/rescue_ws/rescue-beacon-robot
git status --short
git diff --check
git switch fix/md20a-safe-bringup
git add README.md docs firmware hardware/bom/README.md scripts
git commit -m "Align MD20A wiring and make motor bring-up safer"
git push -u origin fix/md20a-safe-bringup
```

게시할 때는 `git status --short`로 포함 파일을 확인하고,
모델 바이너리나 장치별 비밀 파일이 들어가지 않았는지 확인합니다.

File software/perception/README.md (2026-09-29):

# YOLO 탐지 결과 ROS2 연결

`ros_yolo_bridge.py`는 이 장비의 기존
`/home/sunrise/rdk_model_zoo/samples/vision/ultralytics_yolo/runtime/python/ros_yolo_live.py`
노드를 재사용합니다. 화면용 JPEG와 함께 `/rescue_yolo_detections`
(`ai_msgs/msg/PerceptionTargets`)에 탐지 상자를 발행합니다.
모델의 `fallen`, `sit`, `standing` 클래스를 그대로 전달합니다. 카메라 전용
주행 시험은 `fallen`만 목표로 선택하며 `sit`과 `standing`에서는 움직이지
않습니다.
탐지 결과가 없는 프레임도 빈 메시지로 발행합니다.

카메라를 먼저 실행한 뒤 YOLO 터미널에서 저장소 최상위 경로 기준:

```bash
cd ~/rescue_ws/rescue-beacon-robot
bash scripts/run_yolo.sh
```

기존 `python3 ros_yolo_live.py`는 종료하고 위 명령을 실행해야 합니다.
같은 카메라와 모델을 두 프로세스에서 중복 실행하지 않습니다.
이 스크립트는 `~/rdk_model_zoo`의 기존 런타임과
`~/best_bayese_640x640_nv12.bin` 모델을 사용합니다. 해당 파일은 이
저장소에 포함되지 않습니다.

카메라가 180도 뒤집혀 장착돼 있어 `run_yolo.sh`는 기본적으로 입력 영상을
YOLO 추론 전에 180도 회전합니다. 따라서 노트북 모니터 영상과 사람 탐지
상자 좌표가 함께 바로 서며, 좌우 추적 방향도 정상 영상 기준으로 계산됩니다.
카메라 장착 방향이 바뀌면 아래처럼 회전을 끌 수 있습니다.

```bash
bash scripts/run_yolo.sh --ros-args -p rotate_180:=false
```

## YOLO 화면 모니터

기존 YOLO 런타임은 탐지 상자를 그린 JPEG 영상을
`/yolo/image_annotated/compressed`에 발행합니다. 카메라와 YOLO가 실행 중일 때
RDK의 새 터미널에서 아래 명령을 실행하면 브라우저 화면으로 볼 수 있습니다.
이 모니터는 영상·미션 상태·Arduino 연결 상태를 **읽기만** 하며 주행 명령은
보내지 않습니다.

```bash
cd ~/rescue_ws/rescue-beacon-robot
bash scripts/run_yolo_monitor.sh --host 0.0.0.0
```

RDK에 연결된 모니터에서는 `http://127.0.0.1:8088`을 엽니다. Ubuntu 노트북
화면에서는 RDK에서 `hostname -I`로 확인한 LAN 주소를 사용해
`http://<RDK_IP>:8088`을 엽니다. 두 장치는 같은 네트워크에 있어야 합니다.
창에 `영상 대기 중`이 계속 표시되면 카메라와 `run_yolo.sh`가 먼저 실행됐는지
확인합니다. 최종 통합 시험에서는 이 창을 열어 둔 채 로봇을 관찰합니다.

현재 사람 접근 정지는 실제 거리 대신 바운딩박스 높이 비율을 사용합니다.
`software/ros2/rescue_beacon/config/rescue_beacon.yaml`의 영상 크기 1920×1080과
`stop_height_ratio`는 실물 카메라 영상으로 확인해야 합니다.
터미널별 전체 실행 순서는 [대회 실행 안내](../../docs/competition-runbook.md)에
있습니다.

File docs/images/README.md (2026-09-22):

# Images

시스템 아키텍처 다이어그램, 배선도, 실물 사진 등을 이 폴더에 보관합니다.

메인 [README.md](../../README.md)에서 `![설명](docs/images/파일명.png)` 형태로 참조하세요.

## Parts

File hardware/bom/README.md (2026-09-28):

# BOM (Bill of Materials)

부품 목록을 이 폴더에 정리합니다.

- `bom.csv` — 부품명, 수량, 규격, 구매처(디바이스마트, 알리익스프레스 등), 단가, 구매 링크

## 열(column) 예시

| 항목 | 규격 | 수량 | 구매처 | 단가 | 링크 |
|---|---|---|---|---|---|
| RDK X5 | - | 1 | | | |
| Arduino Nano Every | - | 1 | | | |
| Cytron MD20A | - | 2 | | | |
| RB-35GM+Encoder | 12V, 1:75 | 2 | | | |
| YDLIDAR X4 Pro | - | 1 | | | |

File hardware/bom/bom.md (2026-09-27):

# 로봇 재료

| 역할 | 항목 | 규격 | 수량 |
|---|---|---|---|
| 메인 컴퓨터 | RDK X5 | 5V, 5A | 1 |
| 모터 제어부 | Arduino Nano Every | 5V, 5A | 1 |
| 모터 드라이브 | Cytron MD20A | - | 2 |
| LiDAR | YDLIDAR X4 Pro | 5V, 2A | 1 |
| 엔코더 모터 | 42-775B | 22.2V, 감속비 1:75 | 2 |
| IMU 센서 | BNO085 | 3.3V | 1 |
| 오디오 재생 모듈 | DFplayer_Mini | 5V | 1 |
| 오디오 앰프 모듈 | PAM8403 | | 1 |
| 스피커 | - | 4Ω, 3W | 1 |
| RDK 컨버터 | SZH-EK366 | 5V, 5A | 1 |
| LiDAR 컨버터 | SZH-EKBD-066 | 5V, 3A | 1 |

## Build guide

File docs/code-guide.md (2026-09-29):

# 코드 안내

GitHub의 **Code** 탭에서 아래 링크를 누르면 소스 코드를 바로 볼 수 있습니다.
각 파일에는 주요 판단과 안전 동작을 설명하는 한국어 주석을 넣었습니다.
실행 명령과 터미널 순서는 [대회 실행 안내](competition-runbook.md)에 있습니다.

## 먼저 읽을 파일

| 순서 | 파일 | 역할 |
| --- | --- | --- |
| 1 | [실행 설정](../software/ros2/rescue_beacon/config/rescue_beacon.yaml) | 속도, 정지 거리, 토픽, 시간 초과 값 |
| 2 | [미션 제어](../software/ros2/rescue_beacon/rescue_beacon/mission_controller_node.py) | SEARCH → CONFIRM → APPROACH → ALERT, 최종 `/cmd_vel`과 안전 정지 |
| 3 | [사람 추적](../software/ros2/rescue_beacon/rescue_beacon/person_follow_node.py) | YOLO 사람 상자로 회전·접근 명령 계산 |
| 4 | [LiDAR 탐색](../software/ros2/rescue_beacon/rescue_beacon/lidar_nav_node.py) | 장애물 거리를 보고 탐색 명령 계산 |
| 5 | [YOLO 연결](../software/perception/ros_yolo_bridge.py) | 기존 YOLO의 상자를 ROS 메시지로 변환 |
| 6 | [Arduino 연결](../software/ros2/rescue_beacon/rescue_beacon/serial_bridge_node.py) | USB 통신, 펌웨어 확인, 모터·음향 명령 전달 |
| 7 | [Nano Every 펌웨어](../firmware/arduino/rescue_beacon_firmware/rescue_beacon_firmware.ino) | 모터 PWM, 엔코더, 소리 센서, DFPlayer Pro 제어 |
| 8 | [모터 전용 임시 스케치](../firmware/arduino/motor_only_diagnostic/motor_only_diagnostic.ino) | 노트북에서 업로드하고 시리얼 모니터로 좌우 모터를 0.2초씩 확인 |

## 데이터가 흐르는 순서

```text
카메라 → 기존 YOLO → ros_yolo_bridge → person_follow_node ─┐
                                                       ├→ mission_controller_node → /cmd_vel
LiDAR → /scan → lidar_nav_node ──────────────────────────┘            │
                                                                      ├→ /beacon_trigger
                                                                      ↓
                                                   serial_bridge_node → Nano Every
```

`mission_controller_node`만 최종 `/cmd_vel`을 발행합니다. Arduino로 주행 명령을
전달하려면 시리얼 연결과 모터 전달을 각각 켜야 합니다. 기본값은 둘 다 꺼져
있습니다. `ALERT`에 도달하면 정지 상태를 유지하며, 새 탐색은 미션 노드를
재시작해야 시작됩니다.

## 실행과 확인 코드

| 파일 | 용도 |
| --- | --- |
| [ROS 시작 설정](../software/ros2/rescue_beacon/launch/rescue_beacon.launch.py) | 노드를 한 번에 실행하고 Arduino 연결 여부를 선택 |
| [빌드](../scripts/build_ros.sh) | ROS 패키지 빌드 |
| [카메라](../scripts/run_camera.sh) · [YOLO](../scripts/run_yolo.sh) · [LiDAR](../scripts/run_lidar.sh) · [미션](../scripts/run_mission.sh) | 터미널별 실행 명령 |
| [시리얼 단독 실행](../scripts/run_serial_bridge.sh) | Arduino 통신 점검 |
| [YOLO 화면](../scripts/run_yolo_monitor.sh) · [브라우저 모니터](../scripts/yolo_monitor.py) | 탐지 상자 영상과 미션 상태를 브라우저에서 확인; 주행 명령 없음 |
| [Arduino USB 점검](../scripts/arduino_smoke_test.py) | `READY,1`, 엔코더, 소리 입력 확인; 모터에는 0 명령만 전송 |
| [모터 단독 시험](../scripts/arduino_motor_test.py) | 바퀴를 띄운 상태에서 사용자 `RUN` 확인 후 0.5초 저속 명령; ROS 브리지 실제 구동은 별도 미시험 |
| [미션 안전 테스트](../software/ros2/rescue_beacon/test/test_mission_safety.py) · [시리얼 테스트](../software/ros2/rescue_beacon/test/test_serial_bridge.py) | 상태 고정, 센서 시간 초과, 펌웨어 확인 등의 자동 테스트 |

기존 `ros_yolo_live.py` 런타임과 `best_bayese_640x640_nv12.bin` 모델은
RDK의 `~/rdk_model_zoo`와 홈 디렉터리에 있습니다. 이 저장소에는 YOLO를 ROS에
연결하는 코드만 들어 있습니다. [YOLO 연결 설명](../software/perception/README.md)을
참고하세요. 실제 주행 시험 전에 [펌웨어 핀 안내](../firmware/arduino/README.md)와
[현재 하드웨어 시험 상태](competition-runbook.md)를 확인하세요.

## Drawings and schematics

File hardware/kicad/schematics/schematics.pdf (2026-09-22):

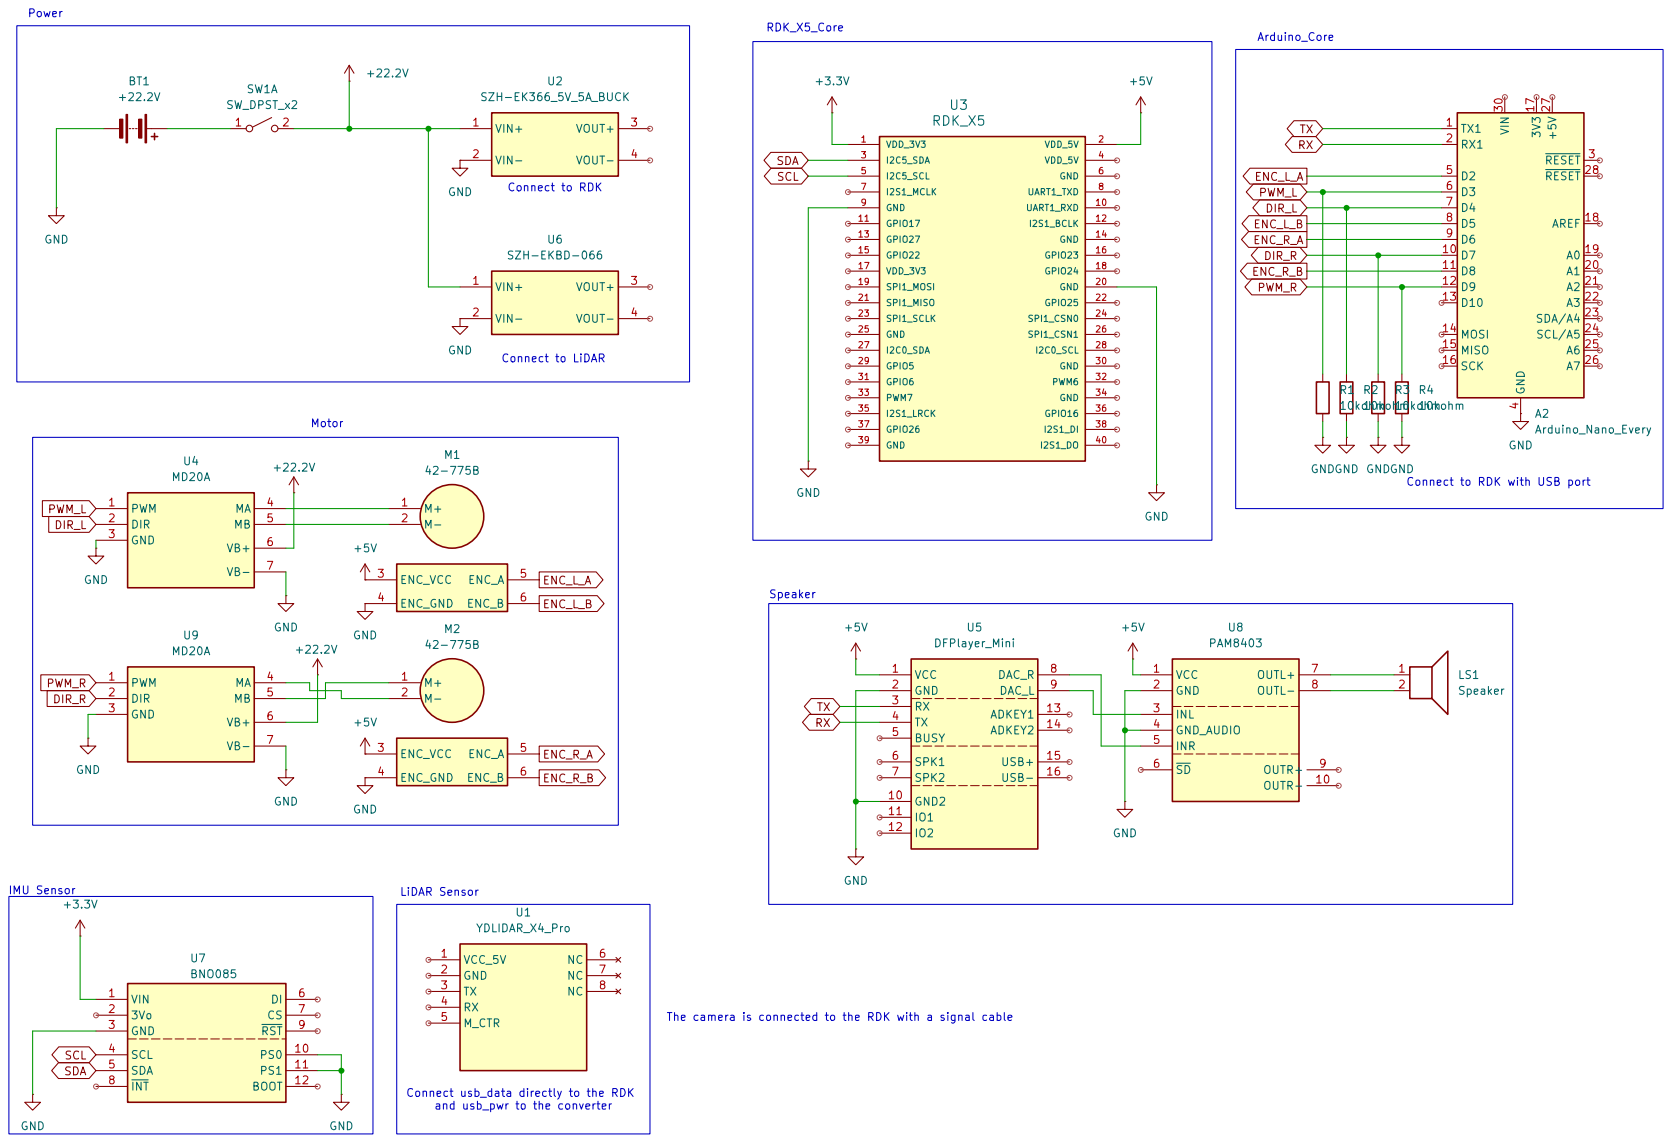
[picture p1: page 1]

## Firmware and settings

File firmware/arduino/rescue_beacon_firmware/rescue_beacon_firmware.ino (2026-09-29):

/*
  구조 비콘 로봇 - Arduino Nano Every, 직렬 프로토콜 버전 1.

  USB Serial, 115200 baud:
    RDK -> Nano: HELLO | CMD,<linear_mps>,<angular_radps> | BEEP,1
    Nano -> RDK: READY,1 | ENC,<left_count>,<right_count> |
                 SOUND,<0_or_1> | ACK,BEEP | ERR,CMD

  아래 핀은 hardware/kicad 회로도의 Arduino_Core 배선에 맞춘 값이다.
  모터 전원을 넣기 전에 실제 연결과 바퀴 방향을 확인한다.
*/

#include <Arduino.h>
#include <math.h>
#include <stdlib.h>
#include <string.h>

// Cytron MD20A 2개의 PWM/DIR 입력. 회로도에서 PWM_L=D3, PWM_R=D9이다.
const uint8_t LEFT_PWM_PIN = 3;
const uint8_t LEFT_DIR_PIN = 4;
const uint8_t RIGHT_PWM_PIN = 9;
const uint8_t RIGHT_DIR_PIN = 7;

// 회로도에서 ENC_L_A/B=D2/D5, ENC_R_A/B=D6/D8이다.
// 엔코더 A 변화는 인터럽트로 세고, 그 순간의 B 값으로 회전 방향을 정한다.
const uint8_t LEFT_ENC_A_PIN = 2;
const uint8_t LEFT_ENC_B_PIN = 5;
const uint8_t RIGHT_ENC_A_PIN = 6;
const uint8_t RIGHT_ENC_B_PIN = 8;

// LM393 디지털 출력. 센서 한 개로는 소리 유무만 알고 방향은 알 수 없다.
const uint8_t SOUND_PIN = 10;
const bool SOUND_ACTIVE_LOW = true;

// 바퀴를 지면에서 띄우고 전진 명령 방향을 확인한 뒤 반전 값을 조정한다.
const bool LEFT_MOTOR_INVERT = true;
const bool RIGHT_MOTOR_INVERT = true;

const float MAX_LINEAR_CMD = 0.20f;
const float MAX_ANGULAR_CMD = 0.70f;
const uint8_t MAX_PWM = 180;
const unsigned long COMMAND_TIMEOUT_MS = 500;
const unsigned long TELEMETRY_PERIOD_MS = 200;

// 실제 장착품은 DFPlayer Pro DFR0768. Serial1은 Nano Every의 RX/TX 핀이다.
// Pro는 Mini의 바이너리 프레임 대신 115200 baud AT 명령을 사용한다.
const uint32_t DFPLAYER_BAUD = 115200;
const uint8_t DFPLAYER_VOLUME = 20;  // Pro 범위: 0..30; 과열 확인 후 최대 음량 사용 중단
// USB-C로 Pro 내장 저장공간의 최상위에 복사한 파일을 재생한다.
const char ALERT_FILE_PATH[] = "/bbibip.mp3";

volatile long leftEncoderCount = 0;
volatile long rightEncoderCount = 0;
unsigned long lastCommandMs = 0;
unsigned long lastTelemetryMs = 0;
char inputLine[64];
uint8_t inputLength = 0;
bool discardLine = false;


float clampf(float value, float low, float high) {
  if (value < low) return low;
  if (value > high) return high;
  return value;
}


void leftEncoderISR() {
  leftEncoderCount += digitalRead(LEFT_ENC_B_PIN) ? 1 : -1;
}


void rightEncoderISR() {
  rightEncoderCount += digitalRead(RIGHT_ENC_B_PIN) ? 1 : -1;
}


void stopMotors() {
  analogWrite(LEFT_PWM_PIN, 0);
  analogWrite(RIGHT_PWM_PIN, 0);
}


void setOneMotor(uint8_t pwmPin, uint8_t dirPin, float command, bool invert) {
  command = clampf(command, -1.0f, 1.0f);
  if (invert) command = -command;
  digitalWrite(dirPin, command >= 0.0f ? HIGH : LOW);
  analogWrite(pwmPin, (uint8_t)(fabs(command) * MAX_PWM));
}


void applyCmdVel(float linear, float angular) {
  // ROS의 전진 속도와 회전 속도를 좌우 바퀴 출력 비율로 변환한다.
  // peak 정규화로 어느 쪽도 PWM 상한을 넘지 않게 한다.
  float left = linear / MAX_LINEAR_CMD - angular / MAX_ANGULAR_CMD;
  float right = linear / MAX_LINEAR_CMD + angular / MAX_ANGULAR_CMD;
  float peak = max(fabs(left), fabs(right));
  if (peak > 1.0f) {
    left /= peak;
    right /= peak;
  }
  setOneMotor(LEFT_PWM_PIN, LEFT_DIR_PIN, left, LEFT_MOTOR_INVERT);
  setOneMotor(RIGHT_PWM_PIN, RIGHT_DIR_PIN, right, RIGHT_MOTOR_INVERT);
}


void playAlert(bool firstFileByNumber = false) {
  // 한 번만 재생하고 정지한다. 각 AT 명령은 CR/LF로 끝나야 한다.
  Serial1.print(F("AT+PLAYMODE=3\r\n"));
  delay(20);
  Serial1.print(F("AT+VOL="));
  Serial1.print(DFPLAYER_VOLUME);
  Serial1.print(F("\r\n"));
  delay(20);
  if (firstFileByNumber) {
    // 실물에서 확인한 재생 방식. Pro의 첫 번째 파일을 재생한다.
    Serial1.print(F("AT+PLAYNUM=1\r\n"));
  } else {
    Serial1.print(F("AT+PLAYFILE="));
    Serial1.print(ALERT_FILE_PATH);
    Serial1.print(F("\r\n"));
  }
  // 이 응답은 재생 명령을 UART로 보낸 사실만 뜻한다. 소리는 별도 확인한다.
  Serial.println(firstFileByNumber ? F("ACK,BEEP2") : F("ACK,BEEP"));
}


bool parseCmd(char *text, float *linear, float *angular) {
  // 숫자 형식, NaN/무한대, 허용 속도 범위를 모두 검사한다.
  char *comma = strchr(text, ',');
  if (comma == NULL) return false;
  *comma = '\0';
  char *end = NULL;
  double v = strtod(text, &end);
  if (end == text || *end != '\0' || isnan(v) || isinf(v)) return false;
  char *angularText = comma + 1;
  double w = strtod(angularText, &end);
  if (end == angularText || *end != '\0' || isnan(w) || isinf(w)) return false;
  if (fabs(v) > MAX_LINEAR_CMD || fabs(w) > MAX_ANGULAR_CMD) return false;
  *linear = (float)v;
  *angular = (float)w;
  return true;
}


void processCommand(char *line) {
  // USB 호스트는 HELLO에 대한 READY,1을 확인한 뒤 명령을 보낸다.
  if (strcmp(line, "HELLO") == 0) {
    Serial.println(F("READY,1"));
    return;
  }
  if (strcmp(line, "BEEP,1") == 0) {
    playAlert();
    return;
  }
  if (strcmp(line, "BEEP,2") == 0) {
    playAlert(true);
    return;
  }
  if (strncmp(line, "CMD,", 4) == 0) {
    float linear = 0.0f;
    float angular = 0.0f;
    if (!parseCmd(line + 4, &linear, &angular)) {
      // 잘못된 CMD를 받으면 기존 주행을 즉시 중단한다.
      stopMotors();
      Serial.println(F("ERR,CMD"));
      return;
    }
    applyCmdVel(linear, angular);
    lastCommandMs = millis();
  }
}


void setup() {
  // 부팅 직후 모터 PWM을 0으로 두고 입력·출력을 초기화한다.
  pinMode(LEFT_PWM_PIN, OUTPUT);
  pinMode(LEFT_DIR_PIN, OUTPUT);
  pinMode(RIGHT_PWM_PIN, OUTPUT);
  pinMode(RIGHT_DIR_PIN, OUTPUT);
  stopMotors();

  pinMode(LEFT_ENC_A_PIN, INPUT_PULLUP);
  pinMode(LEFT_ENC_B_PIN, INPUT_PULLUP);
  pinMode(RIGHT_ENC_A_PIN, INPUT_PULLUP);
  pinMode(RIGHT_ENC_B_PIN, INPUT_PULLUP);
  pinMode(SOUND_PIN, INPUT_PULLUP);
  attachInterrupt(digitalPinToInterrupt(LEFT_ENC_A_PIN), leftEncoderISR, CHANGE);
  attachInterrupt(digitalPinToInterrupt(RIGHT_ENC_A_PIN), rightEncoderISR, CHANGE);

  Serial.begin(115200);
  Serial1.begin(DFPLAYER_BAUD);
  delay(3000);  // DFPlayer Pro가 부팅할 시간을 준다.
  Serial1.print(F("AT+VOL="));
  Serial1.print(DFPLAYER_VOLUME);
  Serial1.print(F("\r\n"));

  lastCommandMs = millis();
  lastTelemetryMs = millis();
  Serial.println(F("READY,1"));
}


void loop() {
  // 너무 긴 직렬 입력은 버리고 모터를 멈춘다.
  while (Serial.available()) {
    char c = (char)Serial.read();
    if (c == '\n') {
      if (!discardLine) {
        inputLine[inputLength] = '\0';
        processCommand(inputLine);
      }
      inputLength = 0;
      discardLine = false;
    } else if (c != '\r' && !discardLine) {
      if (inputLength < sizeof(inputLine) - 1) {
        inputLine[inputLength++] = c;
      } else {
        inputLength = 0;
        discardLine = true;
        stopMotors();
        Serial.println(F("ERR,LINE"));
      }
    }
  }

  // 0.5초 동안 유효한 CMD가 오지 않으면 PWM을 0으로 만든다.
  if (millis() - lastCommandMs > COMMAND_TIMEOUT_MS) stopMotors();

  if (millis() - lastTelemetryMs >= TELEMETRY_PERIOD_MS) {
    // 인터럽트 중간에 32비트 카운트를 읽지 않도록 잠깐 잠근다.
    noInterrupts();
    long left = leftEncoderCount;
    long right = rightEncoderCount;
    interrupts();
    Serial.print(F("ENC,"));
    Serial.print(left);
    Serial.print(',');
    Serial.println(right);
    bool sound = digitalRead(SOUND_PIN) == (SOUND_ACTIVE_LOW ? LOW : HIGH);
    Serial.print(F("SOUND,"));
    Serial.println(sound ? 1 : 0);
    lastTelemetryMs = millis();
  }
}

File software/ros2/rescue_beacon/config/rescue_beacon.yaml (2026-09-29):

lidar_nav_node:
  ros__parameters:
    # LiDAR 탐색 후보 속도. 최종 명령은 mission_controller_node가 결정한다.
    scan_topic: /scan
    output_topic: /search_cmd_vel
    # 실물 LiDAR의 180도 방향이 로봇 정면이다.
    scan_yaw_offset_deg: 180.0
    stop_distance: 0.40
    warning_distance: 0.70
    search_speed: 0.14
    slow_speed: 0.06
    turn_speed: 0.45
    slow_turn_speed: 0.25

person_follow_node:
  ros__parameters:
    # ros_yolo_bridge가 발행하는 원본 1920x1080 영상 좌표를 사용한다.
    detection_topic: /rescue_yolo_detections
    cmd_topic: /person_cmd_vel
    detected_topic: /person_detected
    close_topic: /person_close
    image_width: 1920.0
    image_height: 1080.0
    angular_kp: 0.85
    max_angular: 0.55
    max_linear: 0.14
    min_linear: 0.04
    stop_height_ratio: 0.72
    stop_width_ratio: 0.75
    # 한 프레임의 큰 오탐 상자로 먼 곳에서 ALERT가 되는 것을 막는다.
    close_confirm_frames: 3
    # 대상이 화면 중심에서 크게 벗어나면 전진하지 않고 회전한다.
    rotate_only_error: 0.40
    lost_timeout_sec: 0.7

mission_controller_node:
  ros__parameters:
    # 전방 스캔과 탐지·후보 명령이 오래되면 /cmd_vel을 0으로 만든다.
    search_cmd_topic: /search_cmd_vel
    person_cmd_topic: /person_cmd_vel
    person_detected_topic: /person_detected
    person_close_topic: /person_close
    scan_topic: /scan
    output_topic: /cmd_vel
    scan_yaw_offset_deg: 180.0
    beacon_topic: /beacon_trigger
    state_topic: /mission_state
    confirm_cycles: 3
    lost_cycles: 8
    emergency_stop_distance: 0.50
    caution_distance: 0.70
    scan_timeout_sec: 1.0
    input_timeout_sec: 0.5

serial_bridge_node:
  ros__parameters:
    # 펌웨어 READY,1 확인 후에도 enable_motion=false이면 0 속도만 보낸다.
    port: /dev/ttyACM0
    baud: 115200
    cmd_topic: /cmd_vel
    beacon_topic: /beacon_trigger
    ready_topic: /arduino_ready
    telemetry_topic: /arduino_telemetry
    sound_topic: /sound_detected
    send_rate_hz: 20.0
    reconnect_sec: 2.0
    cmd_timeout_sec: 0.5
    enable_motion: false

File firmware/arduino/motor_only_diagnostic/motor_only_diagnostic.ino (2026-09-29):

/*
  Nano Every + MD20A 2개: 모터만 분리해서 확인하는 임시 스케치.

  업로드와 USB 연결은 모터 배터리 스위치를 끈 상태에서 한다.
  부팅 시 자동 구동하지 않는다. 시리얼 모니터 115200 baud, Newline 설정:
    STATUS -> 현재 명령 상태 확인 (모터 구동 없음)
    ARM    -> 5초 동안 다음 LEFT 또는 RIGHT 명령 한 번 허용
    LEFT   -> 왼쪽만 PWM 60/255로 0.2초 구동
    RIGHT  -> 오른쪽만 PWM 60/255로 0.2초 구동
    STOP   -> 두 PWM 출력을 즉시 0으로 설정

  이 스케치는 MD20A에 실제로 들어간 전압이나 바퀴 정지를 측정하지 못한다.
  명령 없이 바퀴가 돌거나 STOP 후에도 돌면 메인 스위치를 즉시 끈다.
*/

#include <Arduino.h>
#include <string.h>

// 공유 회로도 Arduino_Core와 구조 로봇 본 펌웨어의 핀 배치를 그대로 쓴다.
const uint8_t LEFT_PWM_PIN = 3;
const uint8_t LEFT_DIR_PIN = 4;
const uint8_t RIGHT_PWM_PIN = 9;
const uint8_t RIGHT_DIR_PIN = 7;

// 본 펌웨어의 전진 방향 설정과 같다. 실제 전진 여부는 눈으로 확인한다.
const uint8_t LEFT_FORWARD_LEVEL = LOW;
const uint8_t RIGHT_FORWARD_LEVEL = LOW;
const uint8_t TEST_PWM = 60;                 // 0..255 중 낮은 출력
const unsigned long TEST_TIME_MS = 200;    // 한 번에 최대 0.2초
const unsigned long ARM_TIME_MS = 5000;    // ARM 뒤 5초 이내에만 구동

bool armed = false;
bool pulseActive = false;
unsigned long armedAtMs = 0;
unsigned long pulseStartedMs = 0;
char inputLine[16];
uint8_t inputLength = 0;
bool discardLine = false;


void stopMotors() {
  // Nano Every의 analogWrite(pin, 0)은 출력 LOW로 전환한다.
  analogWrite(LEFT_PWM_PIN, 0);
  analogWrite(RIGHT_PWM_PIN, 0);
  digitalWrite(LEFT_PWM_PIN, LOW);
  digitalWrite(RIGHT_PWM_PIN, LOW);
  pulseActive = false;
}


void startPulse(bool left) {
  // ARM은 구동 한 번에만 적용한다. 반대쪽 PWM은 먼저 0으로 만든다.
  armed = false;
  stopMotors();
  if (left) {
    digitalWrite(LEFT_DIR_PIN, LEFT_FORWARD_LEVEL);
    Serial.println(F("COMMAND,LEFT,200MS"));
  } else {
    digitalWrite(RIGHT_DIR_PIN, RIGHT_FORWARD_LEVEL);
    Serial.println(F("COMMAND,RIGHT,200MS"));
  }
  pulseStartedMs = millis();
  pulseActive = true;
  // 직렬 출력이 지연되더라도 그 시간이 0.2초 제한에 더해지지 않도록 한다.
  analogWrite(left ? LEFT_PWM_PIN : RIGHT_PWM_PIN, TEST_PWM);
}


void processLine(const char *line) {
  if (strcmp(line, "STOP") == 0) {
    armed = false;
    stopMotors();
    Serial.println(F("PWM_ZERO_COMMAND"));
  } else if (strcmp(line, "STATUS") == 0) {
    Serial.println(pulseActive ? F("STATUS,PULSE_ACTIVE") : F("STATUS,IDLE"));
  } else if (strcmp(line, "ARM") == 0) {
    stopMotors();
    armed = true;
    armedAtMs = millis();
    Serial.println(F("ARMED,5S,ONE_PULSE"));
  } else if (strcmp(line, "LEFT") == 0 || strcmp(line, "RIGHT") == 0) {
    if (!armed || millis() - armedAtMs > ARM_TIME_MS) {
      armed = false;
      stopMotors();
      Serial.println(F("NOT_ARMED"));
      return;
    }
    startPulse(strcmp(line, "LEFT") == 0);
  } else {
    armed = false;
    stopMotors();
    Serial.println(F("UNKNOWN_COMMAND,PWM_ZERO"));
  }
}


void setup() {
  // 출력 모드로 바꾸기 전에 LOW를 래치한다. 부팅 시 자동 구동은 없다.
  digitalWrite(LEFT_PWM_PIN, LOW);
  digitalWrite(RIGHT_PWM_PIN, LOW);
  digitalWrite(LEFT_DIR_PIN, LOW);
  digitalWrite(RIGHT_DIR_PIN, LOW);
  pinMode(LEFT_PWM_PIN, OUTPUT);
  pinMode(RIGHT_PWM_PIN, OUTPUT);
  pinMode(LEFT_DIR_PIN, OUTPUT);
  pinMode(RIGHT_DIR_PIN, OUTPUT);
  stopMotors();
  Serial.begin(115200);
  Serial.println(F("MOTOR_ONLY_READY; SEND STATUS"));
}


void loop() {
  // 구동 중에도 입력을 받아 STOP을 처리하고, 0.2초가 지나면 자동으로 끈다.
  if (pulseActive && millis() - pulseStartedMs >= TEST_TIME_MS) {
    stopMotors();
    Serial.println(F("PWM_ZERO_COMMAND; VERIFY_WHEEL_STOPPED"));
  }
  if (armed && millis() - armedAtMs > ARM_TIME_MS) {
    armed = false;
    Serial.println(F("ARM_EXPIRED"));
  }

  while (Serial.available()) {
    // 입력이 연속해서 들어오는 중에도 구동 시간 상한을 확인한다.
    if (pulseActive && millis() - pulseStartedMs >= TEST_TIME_MS) {
      stopMotors();
      Serial.println(F("PWM_ZERO_COMMAND; VERIFY_WHEEL_STOPPED"));
    }
    char c = (char)Serial.read();
    if (c == '\n' || c == '\r') {
      if (!discardLine && inputLength > 0) {
        inputLine[inputLength] = '\0';
        processLine(inputLine);
      }
      inputLength = 0;
      discardLine = false;
    } else if (!discardLine) {
      if (inputLength < sizeof(inputLine) - 1) {
        inputLine[inputLength++] = c;
      } else {
        // 긴 입력을 명령 일부로 해석하지 않고 줄 끝까지 버린다.
        inputLength = 0;
        discardLine = true;
        armed = false;
        stopMotors();
        Serial.println(F("LINE_TOO_LONG,PWM_ZERO"));
      }
    }
  }
}

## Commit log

2026-09-22 초기 커밋: KiCad 회로도 및 프로젝트 구조 추가
    [rescue-beacon-robot.kicad_pcb, rescue-beacon-robot.kicad_sch]
2026-09-22 각 폴더에 안내용 README 추가
2026-09-22 회로도 PDF 및 스키매틱 업데이트 추가, KiCad 락/자동저장 파일 gitignore 처리
    [rescue-beacon-robot.kicad_sch]
2026-09-22 회로도 사소한 오류 수정
2026-09-22 회로도 수정
    [rescue-beacon-robot.kicad_sch]
2026-09-22 archive: add initial lidar navigation prototype
2026-09-27 Align MD20A wiring and make motor bring-up safer
2026-09-27 Add guarded Nano Every motor-only diagnostic sketch
2026-09-27 Add motor-free encoder diagnostic
2026-09-27 README 하드웨어 표 업데이트 및 BOM 문서 추가
2026-09-27 Rotate upside-down camera frames before YOLO inference
2026-09-27 Align LiDAR front sector and stop near obstacles
2026-09-28 Add read-only LiDAR scan diagnostic
2026-09-28 Report LiDAR invalid-range breakdown over ten scans
2026-09-28 Compare raw LiDAR point cloud with scan ranges
2026-09-28 Show LiDAR return angles for alignment checks
2026-09-28 Report front LiDAR stability before motion trials
    [check_lidar_scan.py]
2026-09-28 Isolate search steering and clean trial shutdown
2026-09-28 Add direct LiDAR SDK distance diagnostic
2026-09-28 Add bounded camera-only person approach trial
2026-09-28 Allow bounded camera approach until visual arrival
2026-09-28 Require stable visual proximity before camera arrival
2026-09-28 Add stationary camera stop distance sampler
2026-09-28 Record audio amp overheat and restore safe default volume
    [rescue_beacon_firmware.ino]
2026-09-29 Add DFPlayer first-track audio diagnostic
2026-09-29 Use verified DFPlayer first-track command for ROS beacon
2026-09-29 Add supervised audio trial and correct left motor direction
    [motor_only_diagnostic.ino, rescue_beacon_firmware.ino, run_integrated_stand_test.py]
2026-09-29 Document verified camera-only approach and audio result
